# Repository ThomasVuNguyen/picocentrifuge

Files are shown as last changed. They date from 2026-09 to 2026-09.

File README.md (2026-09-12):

# PicoCentrifuge

A 3D printed centrifuge for PBMC separation, run by a Raspberry Pi Pico.
Part of the Bloom wet lab loop.

Read GOAL.md first. BOM.md is the source of truth for parts.

Why this exists: blood goes in, PBMC comes out, PBMC meets the peptide, we find out if
the algorithm was right. This is the cheapest link in that chain and it should not be
the one that costs $3000.

- `GOAL.md` - the contract. question, deadline, artifact, kill date.
- `BOM.md` - parts. have / ordered / need / failed.
- `LOG.md` - build log, newest first.
- `logs/` - voice notes and transcripts.
- `photos/` - dated photos. the timestamp is the log entry.
- `posts/` - drafts. friday opens a PR here on fridays.
- `failed-iterations/` - dead designs. kept for the writeup, never pulled from.

CAD lives in Onshape, document "ComfyBloom", assembly tab "Centrifuge Assembly".

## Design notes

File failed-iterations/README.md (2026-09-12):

# Failed iterations

Dead centrifuge designs. Kept because the failure is the interesting part and it belongs
in the post. Do not pull numbers, parts or STLs out of here into the live build.

## BLOOM-2-fusion (Aug 2026)

Swinging-bucket design, four 15 mL conicals, generated in Fusion 360 by an agent off a
Jira ticket. Complete on paper: parametric file, STEP, nine STLs, assembly drawing, BOM,
and a reproducible Fusion API build script. Never built.

Design point was 150 mm tube radius, 1545 rpm, 400.3 x g, which needed a containment
vessel with 466 mm clear inside diameter. That is a restaurant stock pot.

Why it died: [***]

## loose-assets

Orphaned exports that were sitting in comfybloom/assets: an early CAD render and two
STLs (base, rotor). No matching source file. Moved here rather than deleted.

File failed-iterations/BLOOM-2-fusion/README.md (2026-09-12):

# BLOOM-2 swinging-bucket centrifuge

Fusion 360 prototype for Ficoll/PBMC separation using four 15 mL conical tubes.

## Design point

- Tube mid-fluid radius: **150 mm**
- Exact calculated speed for 400 x g: **1544.4 rpm**
- Controller setpoint: **1545 rpm**
- Resulting RCF: **400.3 x g**
- Swing pivot radius: **86 mm**
- Rotor tip radius at speed: **218 mm**
- Minimum steel-pot inside diameter: **466 mm** (includes 15 mm radial clearance)

The four buckets are modeled in the at-speed horizontal position. Each bucket
rotates about an M3 tangential pivot and has a printed tab that contacts the arm
at 90 degrees. The clevis has 0.5 mm nominal side clearance to the 26 mm bucket
envelope. Use low-friction washers and tighten the nylock only enough to remove
axial play without pinching the bucket.

## Files

- `BLOOM-2_centrifuge_parametric.f3d` - Fusion archive with user parameters,
  shared arm/bucket components, named bodies, and the driven radius reference
- `BLOOM-2_centrifuge_assembly.step` - neutral assembly export
- `stl/` - printable parts; filenames state quantities or option
- `views/` - verified Fusion assembly views
- `bom.csv` - printed and purchased bill of materials
- `build_fusion.py` - reproducible Fusion API build script
- `../../../output/pdf/BLOOM-2_centrifuge_assembly_drawing.pdf` - assembly drawing,
  dimensions, BOM, print notes, and validation plan

## Print setup

- Material: PETG only; dry filament before printing.
- Chassis, hub, and arm: print flat as exported, 0.2 mm layers, 6 perimeters,
  8 top/bottom layers, 70-100% infill. Use 100% around bolt and pivot zones.
- Bucket: print on its side as exported so the principal tensile load runs in
  the layer plane. Use supports under the pivot lug and bore; 6 perimeters and
  100% infill at the lug/stop.
- Print all four arms in one job and all four buckets in one job with identical
  slicer settings. Deburr without removing asymmetric amounts of material.
- Match printed buckets to **+/-0.5 g**. Match opposing loaded tubes to
  **+/-0.1 g** before every run.

## Assembly

1. Press two 608ZZ bearings into the 22.2 mm chassis seats and preload them on
   the 8 mm shaft without side-loading either bearing.
2. Bolt four identical arms to the hub using two M3 fasteners per arm.
3. Install each bucket with an M3x45 pivot, two low-friction washers, and a
   nylock nut. Verify every empty bucket falls freely from vertical to the same
   hard stop by gravity alone.
4. Fit either the direct-drive plate/coupler or the offset 12T:60T gear plate.
   The same four-hole hub interface accepts either configuration.
5. Mount the IR sensor on the tall boss with a 4-8 mm gap to the underside
   target. Mount the MPU-6050 rigidly on the two-hole chassis boss.
6. Install the assembly inside a lidded steel pot with at least 466 mm clear ID.

## Drivetrain notes

Start with direct drive only if the A2212/30 A sensorless ESC starts the fully
loaded rotor smoothly and holds 1545 rpm without desynchronization. Configure a
smooth throttle ramp and coast-only stop; disable active braking. If direct
drive stutters, use the 12T:60T 5:1 option. The included gear STLs are mounting
and fit prototypes with simplified teeth; regenerate/verify true module-1
involute profiles before sustained running.

## Validation gate

This is an engineering prototype, not a certified medical device. Do not begin
with blood. First verify fastener retention, free/equal swing, empty balance,
loaded balance, sensor shutdown, containment, and a guarded overspeed test.
Then run four mass-matched tubes with dyed water over glycerol for 30 minutes at
1545 rpm and coast for more than two minutes. A clean interface is the pass
condition; a smeared or absent interface is a fail.

Made by Codex GPT 5.6 Sol High

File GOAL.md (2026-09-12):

# PicoCentrifuge

PROBLEM STATEMENT:

The Bloom wet lab loop needs PBMC out of whole blood. That needs a centrifuge holding
400 x g for 30 minutes with a slow coast. Used lab centrifuges run $800 to $3000.
I already own the motor, the ESC, the Pico and a printer.

WHAT I AM BUILDING:

A 3D printed centrifuge. Brushless motor sitting in the base housing, 5x8 coupler up to
an 8 mm rod, bearings in a holder, four-arm rotor on top. Speed held closed loop by a
Raspberry Pi Pico reading an IR tach. MPU-6050 on the chassis for imbalance shutdown.
Runs inside a lidded containment vessel.

CAD OF RECORD:

Onshape, document "ComfyBloom", workspace Main, assembly tab "Centrifuge Assembly".
458 instances. Tabs: Centrifuge, Components, Base, 5X8_COUPLER, Centrifuge Assembly.

URL: https://cad.onshape.com/documents/7f68ca2c53fefee57657ef1a/w/1be7287435b32af101e9f2c0/e/be93f421865ffb81668b9cbd

This is the only live design. Everything in failed-iterations/ is dead, do not pull
numbers out of it.

DESIGN POINT:

The requirement is 400 x g at the tube mid-fluid line, held 30 minutes, coast over
2 minutes. RPM falls out of whatever the real rotor radius is:

    rpm = sqrt( RCF / (1.118e-5 * r_cm) )

- Tube mid-fluid radius: [***] measure it off the Onshape assembly
- Setpoint rpm: [***] compute from the above, then round to the controller step
- Material: PETG only, dried

Do not carry the 150 mm / 1545 rpm numbers forward. Those belong to a dead design.

OUTCOME:

A clean Ficoll interface on a dyed-water-over-glycerol run at the setpoint for 30 min.
Smeared or absent interface is a fail. That is the only pass condition that matters.

FRIDAY CONTRACT:

- QUESTION: can a printed rotor on the A2212 hold the setpoint loaded and balanced for 30 min?
- DEADLINE: [***] must be external. grant deadline, a call with a lab, or a date I say
  out loud to Javi at standup. a date I set for myself is an intention, not a deadline.
- ARTIFACT: posts/ writeup, published whether it works or not
- FEEDS: bloom wetlab loop, maker press (SERVO / Hackaday), O-1A original contribution
- KILL DATE: [***]
- BLOCKED-ON-SHIPMENT is a valid state, it is not a stall

VALIDATION GATE:

No blood until all of these pass, in order:

1. fastener retention after 10 min unloaded
2. rotor runs true, no visible wobble at setpoint
3. empty balance, then loaded balance at +/-0.1 g on opposing tubes
4. MPU-6050 shutdown triggers on a deliberate imbalance
5. guarded overspeed test with the lid closed
6. dyed water over glycerol, setpoint, 30 min, coast over 2 min

Engineering prototype, not a certified device. Lid closed for every powered test.

OPEN DESIGN QUESTIONS:

- The assembly has modeled bearings (INNER RACE, OUTER RACE, RETAINER, 8 balls). Are
  those getting printed, or are they a fit model for a real 608 / 8 mm bearing? Printed
  races at 1500+ rpm under a loaded rotor is the thing I would not risk.
- Containment vessel: what is it and what is the clear ID. This killed the last design.
- Rotor is fixed-angle in the render, not swinging. Confirm that is intentional; it
  changes the interface quality on a Ficoll gradient.

NOTES FOR AI AGENTS:

- BOM.md is the source of truth for parts, not the CAD. Reconcile, do not generate.
- Do not write into this file unless I ask, or unless filling a [***].

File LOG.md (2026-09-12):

# Log

Newest first. Voice notes go in logs/ and get transcribed. Photos go in photos/, dated,
no captions needed.

## 2026-09-11 - moved to Onshape, BLOOM-2 retired

Rebuilt the whole thing in Onshape. Document "ComfyBloom", assembly "Centrifuge Assembly",
458 instances. Different architecture: motor sits in the base housing with the ESC, 5x8
coupler up to an 8 mm rod, bearings in a holder, four-arm rotor on top. M4 hardware.

BLOOM-2 and the loose STLs moved to failed-iterations/. Nothing gets pulled out of there.

## 2026-08-09 - BLOOM-2 finished on paper, never built

Agent-generated swinging-bucket design in Fusion off a Jira ticket. Complete package:
parametric file, STEP, nine STLs, assembly drawing, BOM, build script. Needed a 466 mm
clear ID containment vessel. Dead.

## 2026-08-08 - A2212 ramp test on Pico

Motor and ESC ran clean off a MicroPython ramp script. No load, no rotor. Confirmed the
drivetrain is not the hard part.

## 2026-08-08 - decided to build rather than buy

Used lab centrifuges run $800 to $3000. I already own the motor, ESC, Pico and printer.
Stripped it to the physical function: hold 400 x g for 30 minutes with a slow coast and
do not throw a tube. That is a motor, a balanced rotor, a speed loop and a lid.

## Open blockers

1. blood sample and tumor sample
2. containment vessel, clear ID still unknown

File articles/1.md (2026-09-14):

PicoCentrifuge - a DIY centrifuge with Raspberry Pi Pico
=======================================================
Sep 13, 2026 · Budget: $50

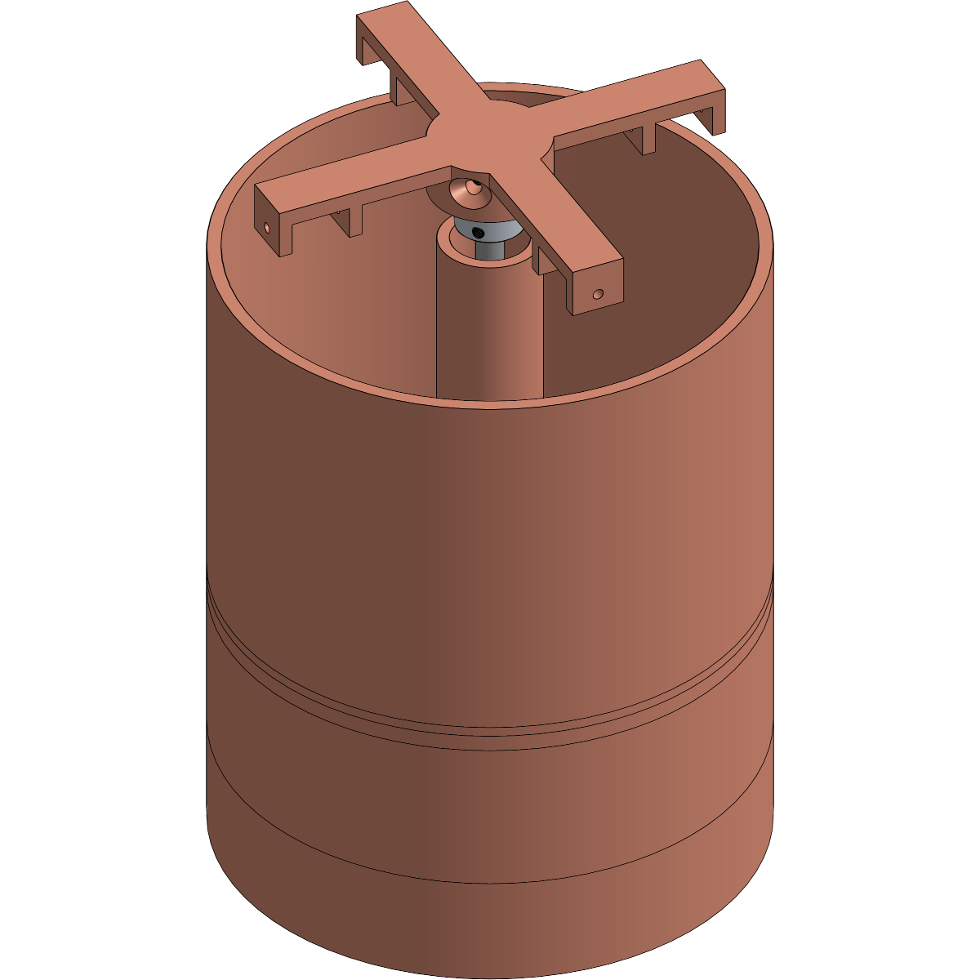
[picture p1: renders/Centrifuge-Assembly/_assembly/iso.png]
PicoCentrifuge full assembly


A centrifuge for blood processing. Drone motor, a Pico, and a 3D printer.

---

## Background

3 days ago was marking 13 years of my mom passing. The moment cancer took her away, I realized it's my life mission to find the definitive cure for cancer.

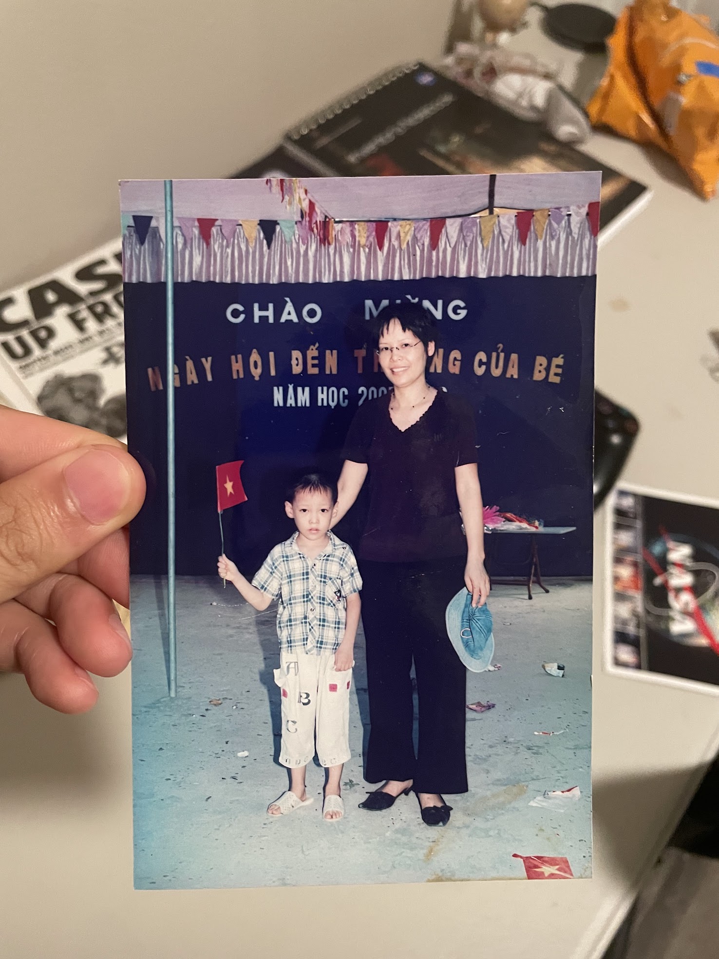
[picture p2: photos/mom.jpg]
Mom


That goal has not changed. What I'm building here is a part of an experiment to create customized neoantigens to kill specific cancer cells in specific few people. 

I'm building [Bloom](https://github.com/ThomasVuNguyen/comfybloom). It takes a patient's sequencing data, finds the mutations, predicts which peptides will trigger an immune response. That part is software. Proving it works is wet lab.

The wet lab loop is simple. Show a peptide to T cells and see if they react:

- Get the T cells. Draw blood, spin it over a density gradient, pull the PBMC layer
- Keep them alive. 37°C, sterile, fed
- Introduce the peptide. Synthesized peptide + cells in a well
- Read the response. Did they secrete IFN-γ? ELISpot plate tells you

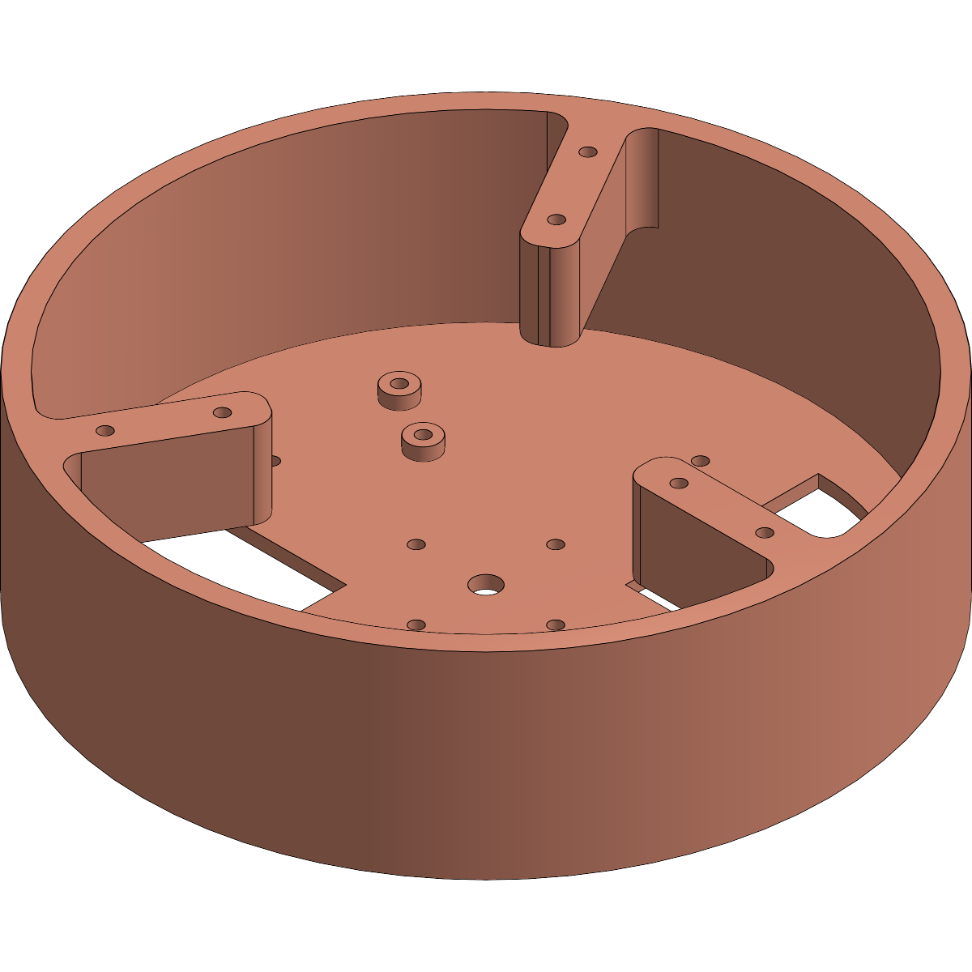
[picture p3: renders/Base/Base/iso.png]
The base housing - motor mounts in the center, ESC tucks underneath


Step 1 is a centrifuge. A used lab centrifuge that fits 15 mL conical tubes goes for $800-$3,000 on eBay. That's the most expensive piece in a DIY wet lab that otherwise costs under $500 from Amazon.

I already own an A2212 brushless motor, a 30A ESC, a Raspberry Pi Pico, and a 3D printer.

The physics is simple. Spin tubes in a circle fast enough that centripetal acceleration separates blood by density. PBMC isolation over Ficoll needs about 400 × g for 30 minutes with a slow coast down.

So I'm building one.

---

## The first design that died

I gave an AI agent a task: design a swinging-bucket centrifuge for four 15 mL conicals at 400 × g. It came back with a complete package in Fusion 360. Parametric file, STEP exports, nine STLs, assembly drawing, BOM, build script. On paper it was beautiful.

On paper it also needed a containment vessel with a 466 mm clear inside diameter. That's an 18-inch restaurant stock pot. The rotor radius was 150 mm, which put the setpoint at 1,545 rpm. Reasonable for the motor, but the whole assembly was enormous. Half the bench gone.

I stared at that for a while and moved on. That design lives in `failed-iterations/BLOOM-2-fusion`. I keep dead designs around because the failure is the interesting part.

---

## What I'm actually building

I rebuilt everything from scratch in Onshape. Much more compact.

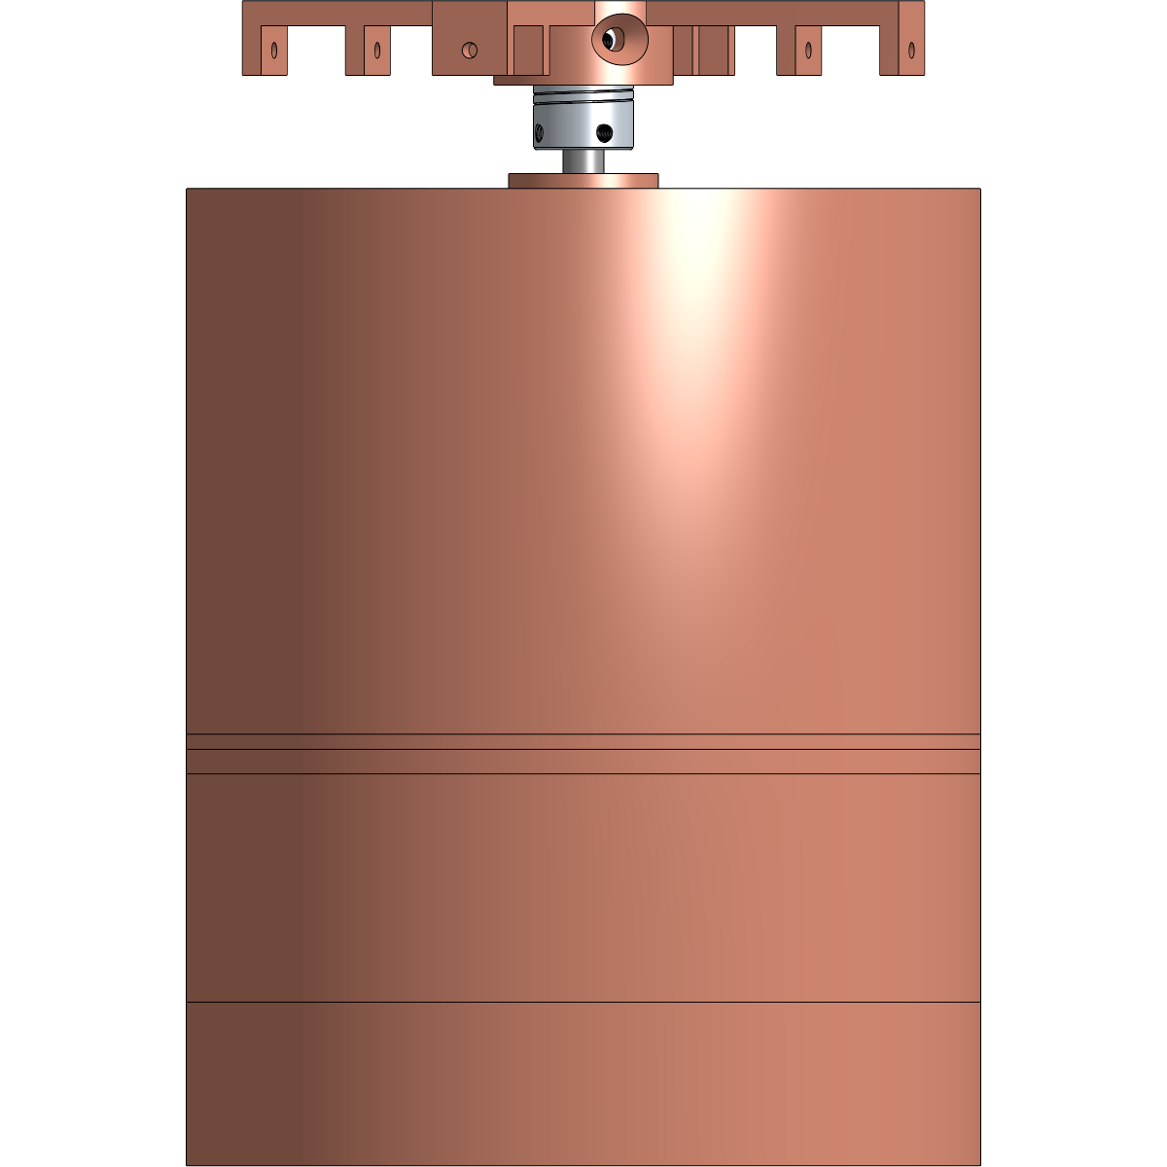
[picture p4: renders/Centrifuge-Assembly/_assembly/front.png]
Front view - you can see the rotor on top, coupler and rod in the middle, containment pot around it, base housing at the bottom


Motor sits in the base housing with the ESC. A 5-to-8 mm rigid coupler goes up to an 8 mm steel rod. Bearings in a holder. Four-arm rotor on top. Whole thing sits inside a containment pot.

Fixed-angle design instead of swinging-bucket. You get a slanted interface on a Ficoll gradient and a harder draw with the pipette. Trade-off is worth it. Mechanically simpler, shorter, easier to balance. For a first prototype, simple wins.

Here's the real thing coming together. Motor, coupler, rod, wiring, all sitting inside the printed base:

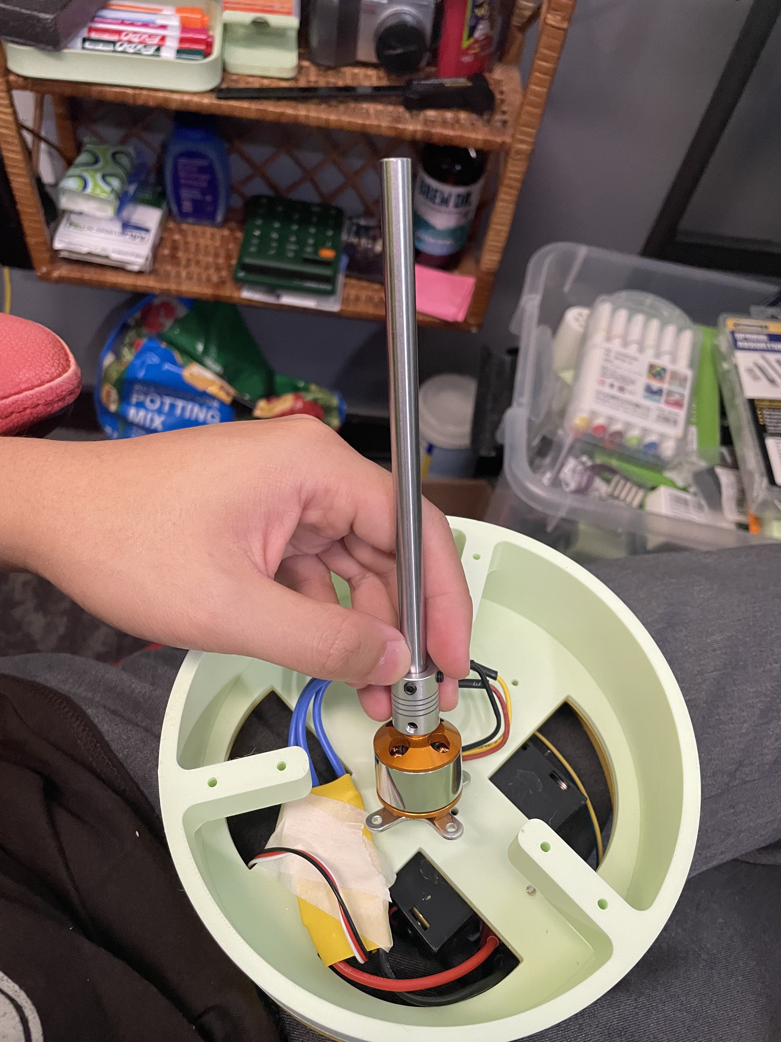
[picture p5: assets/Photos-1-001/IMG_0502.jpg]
Motor installed in the base - A2212 with the coupler and steel rod, ESC wiring tucked inside


And the fully assembled unit, lid closed:

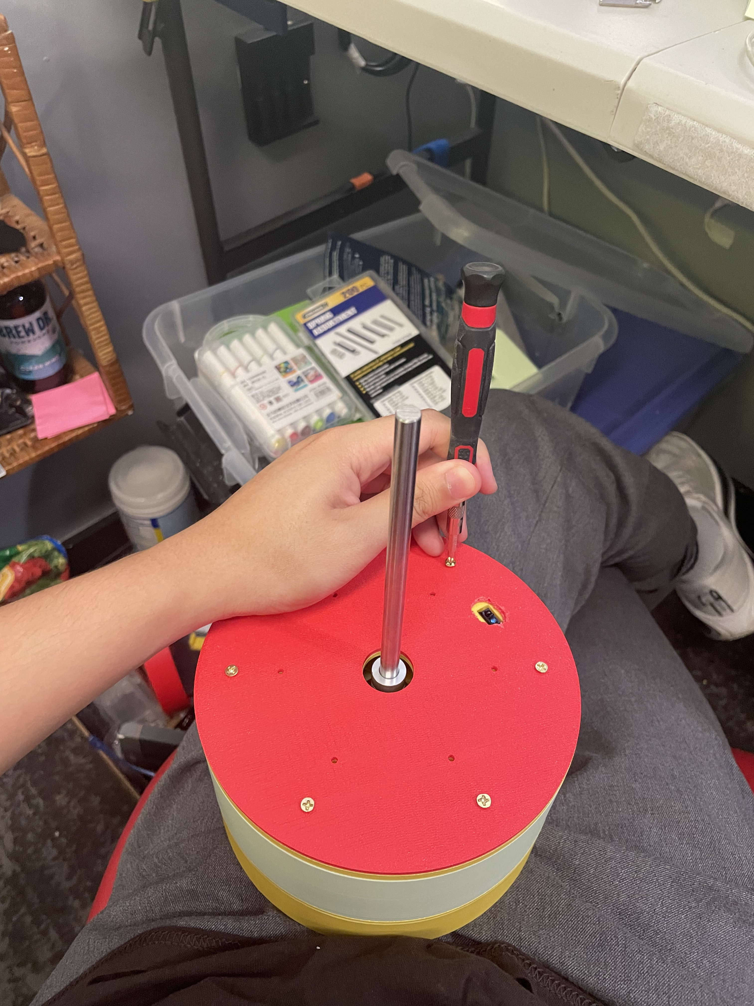
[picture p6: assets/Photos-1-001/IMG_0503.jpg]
Assembled PicoCentrifuge - lid screwed down, rod sticking out the top, ready for the rotor


---

## The rotor

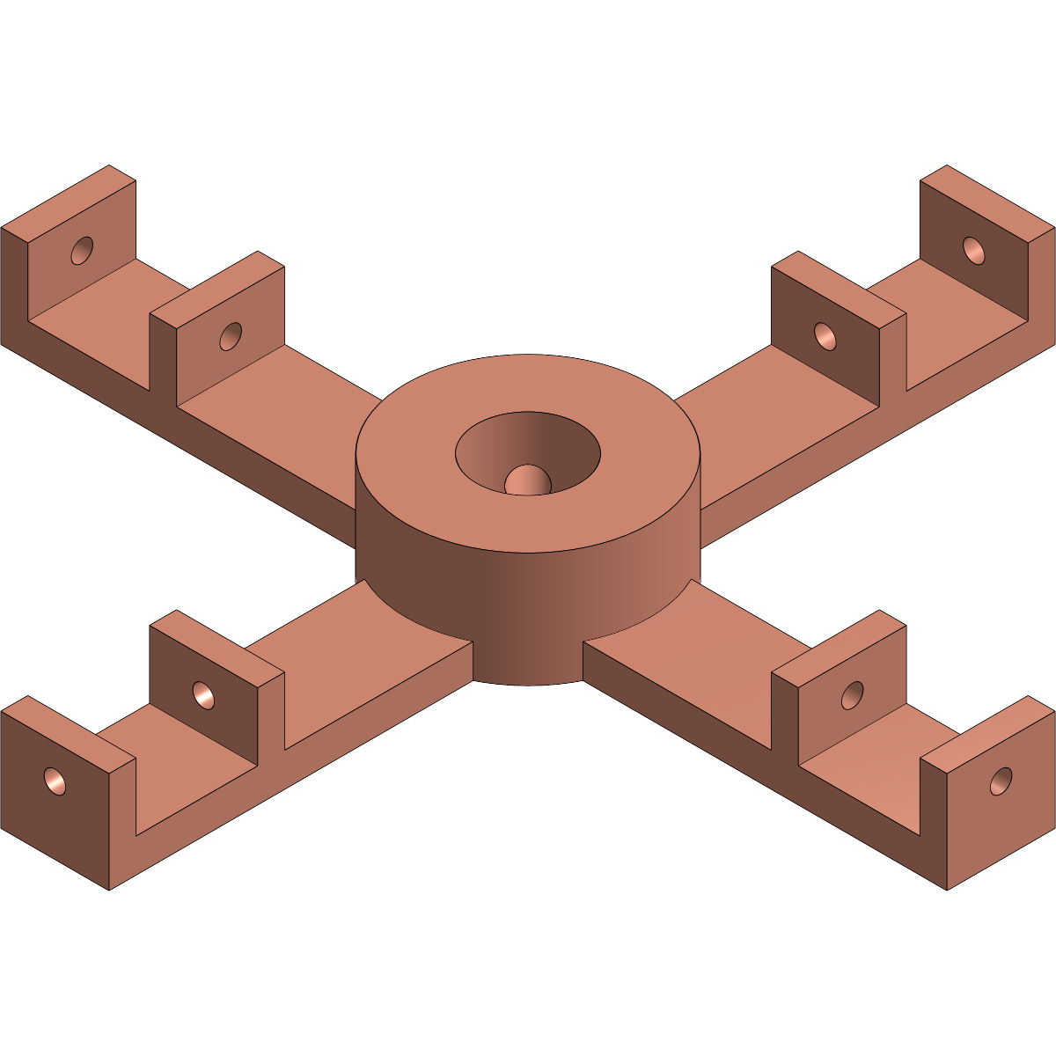
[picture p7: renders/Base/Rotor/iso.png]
Four-arm rotor - each arm cradles a 15 mL conical tube


Four-arm cross, 3D printed in PETG. Each arm holds a 15 mL conical tube (17 × 120 mm). Opposing tubes need to be matched to within ±0.1 g. Imbalance at 1,500+ rpm is how you throw a tube through a wall.

The rotor radius (center of rotation to mid-fluid line) determines the RPM setpoint:

```
rpm = sqrt( RCF / (1.118e-5 × r_cm) )
```

At 400 × g, smaller radius = higher RPM. The exact number comes from measuring the real rotor off the Onshape assembly.

---

## The drivetrain

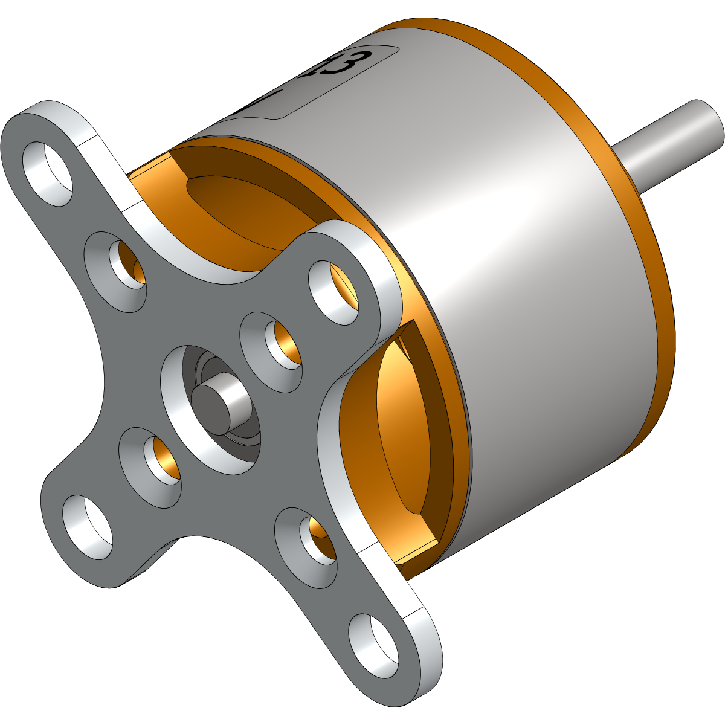
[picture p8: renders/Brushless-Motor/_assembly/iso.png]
A2212 brushless motor - this is a drone motor, way more torque than I need


The A2212/1000KV is a drone motor. Rated for way more RPM than I need. The ESC has brake disabled and a smooth ramp programmed. You do not hard-brake a centrifuge, ever. Coast over 2 minutes minimum, or you disturb the gradient you just spent 30 minutes forming.

Here's the actual motor with the 5-to-8 mm coupler already attached. You can read "A2212/1000KV" right on the label:

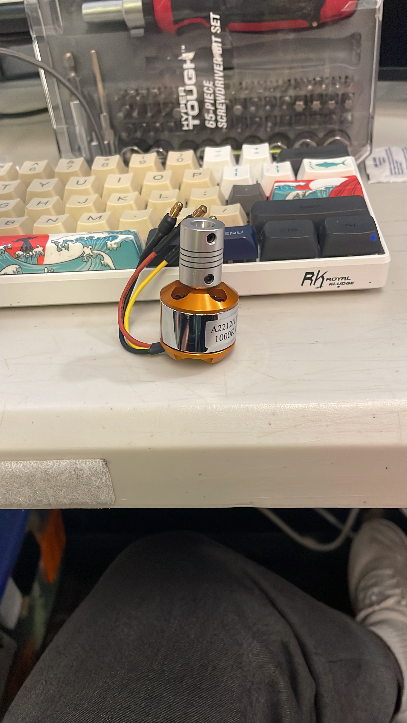
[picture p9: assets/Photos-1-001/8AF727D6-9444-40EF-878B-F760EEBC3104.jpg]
The real A2212 motor with coupler attached, sitting on my desk


I tested the motor and ESC on the Pico before designing anything else. MicroPython ramp script, no load, no rotor. Just confirming the drivetrain works:

```python
from machine import Pin, PWM
import time

esc = PWM(Pin(1))
esc.freq(50)

def us(val):
    esc.duty_u16(int(val / 20000 * 65535))

# arm
us(1000)
time.sleep(3)

# ramp up
for throttle in range(1060, 1300, 20):
    us(throttle)
    time.sleep(2)

# ramp down
for throttle in range(1300, 1040, -20):
    us(throttle)
    time.sleep(2)

us(1000)
time.sleep(1)
esc.deinit()
```

Ran clean. The motor coils sing at higher throttle. That's normal, not an alarm.

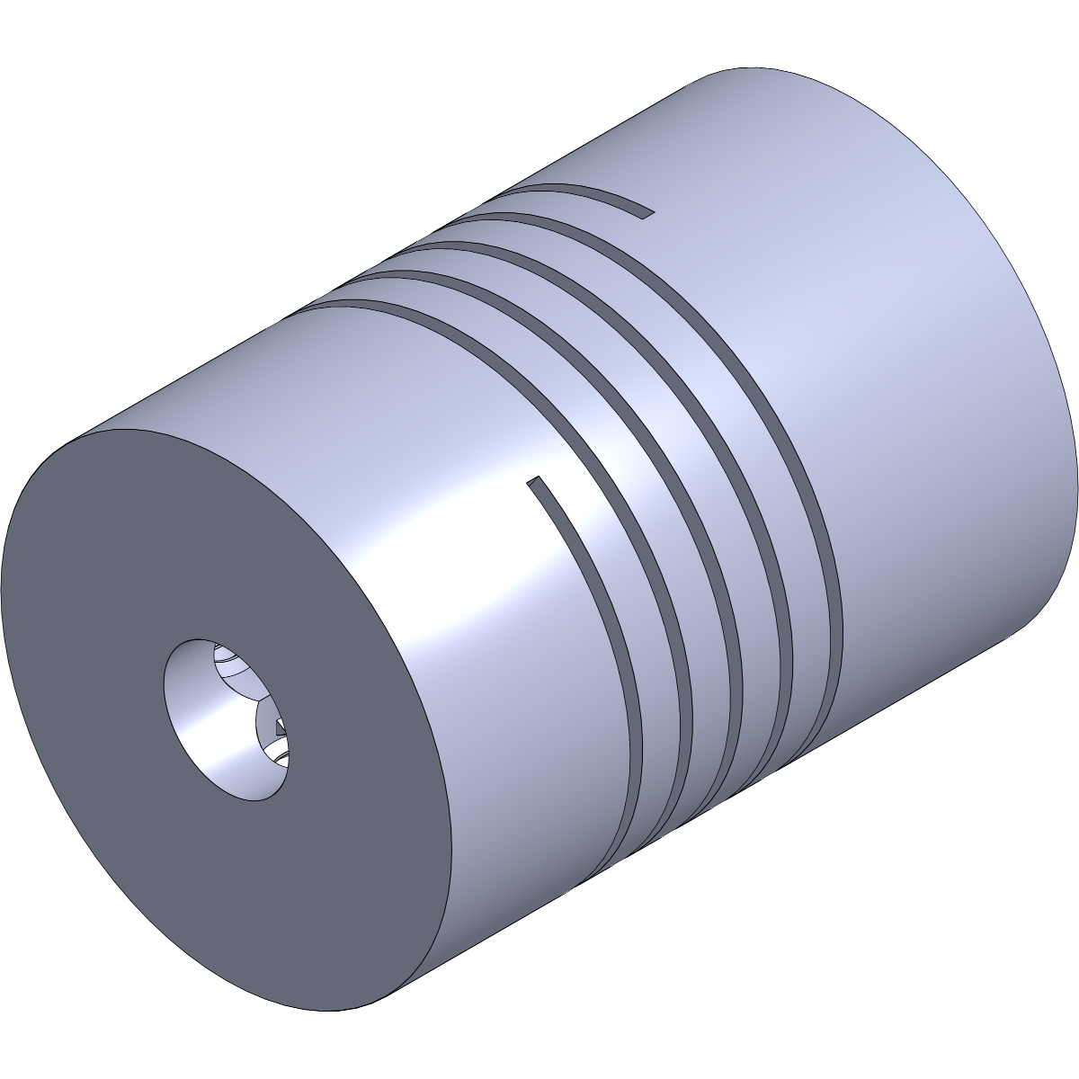
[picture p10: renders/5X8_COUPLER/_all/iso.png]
The 5-to-8 mm coupler - connects the motor shaft to the steel rod


And the aluminum couplers I ordered. These are the real ones, not printed:

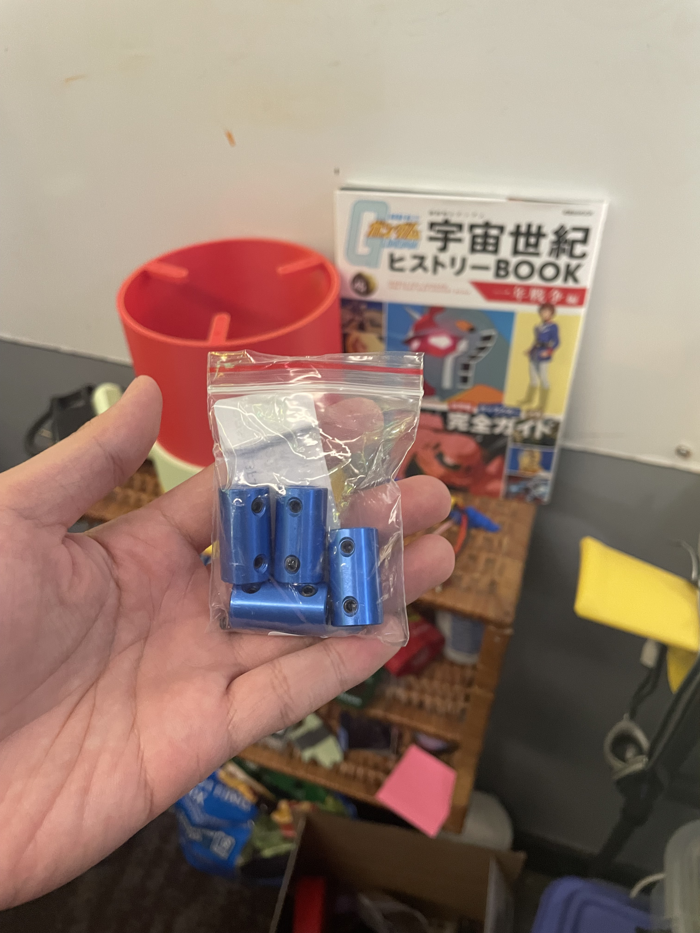
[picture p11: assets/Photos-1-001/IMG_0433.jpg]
5-to-8mm aluminum rigid couplers - buy these, do not print them


---

## Speed control

The setpoint RPM needs to be held closed-loop for 30 minutes. IR reflective sensor pointed at the underside of the rotor gives a tach signal. The Pico counts pulses and adjusts the ESC throttle to maintain target. Textbook PID loop.

---

## Safety

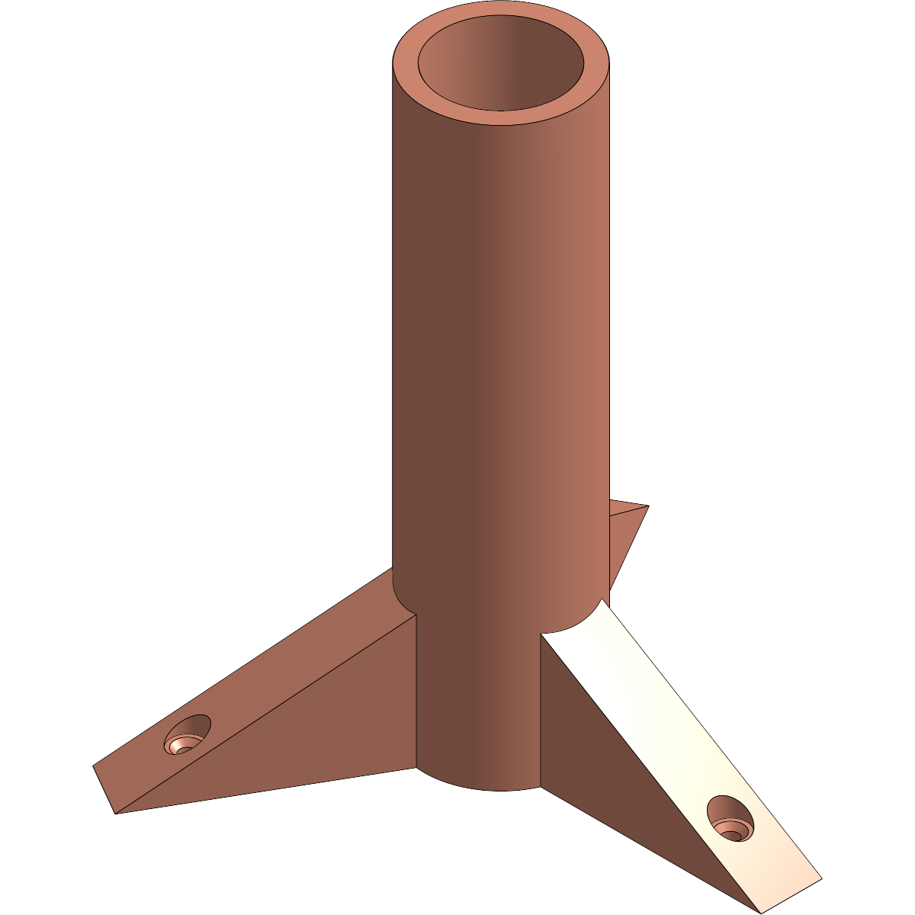
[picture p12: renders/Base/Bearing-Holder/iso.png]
Bearing holder - this sits between the base and the rotor, holds the 8mm rod steady


MPU-6050 accelerometer/gyro sits on the chassis. Flat, rigid, bolted near the bearing holder. NOT on the rotor. It's a vibration sensor: if something comes loose or a tube shifts, vibration signature changes and the Pico cuts motor power. Imbalance shutdown.

The whole assembly runs inside a lidded containment vessel. Lid closed for every powered test, no exceptions.

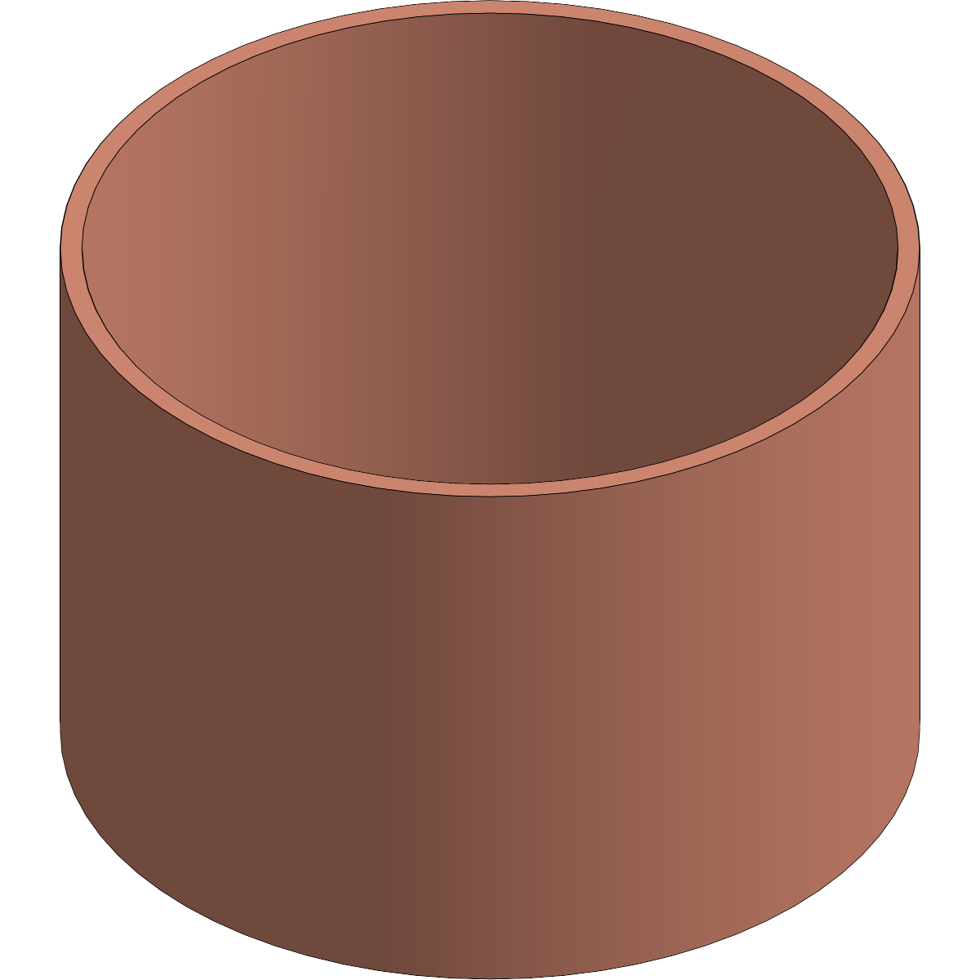
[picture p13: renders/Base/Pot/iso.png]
Containment pot - everything spins inside this


---

## Printing

All structural parts are PETG on the Bambu A1 mini. Filament has to be dried or you get moisture bubbles that become stress risers at speed. Not optional.

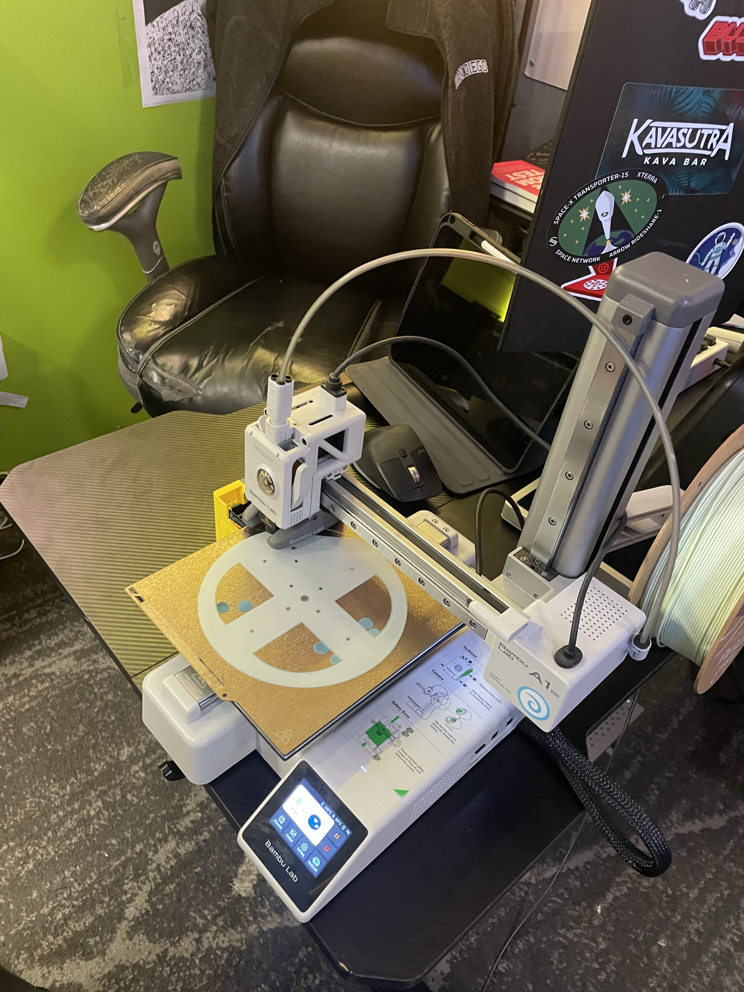
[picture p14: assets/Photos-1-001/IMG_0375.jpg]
Printing the base on the Bambu A1 mini


Opposing rotor arms are printed in the same job so they shrink identically. Matched sets, not mix and match.

---

## The parts

What I already have:

| Part | Notes |
|---|---|
| [A2212 brushless motor (1000 KV, 5 mm shaft)](https://www.amazon.com/dp/B0D2W24DFX) | Ramp tested, ran clean |
| [30A sensorless ESC](https://www.amazon.com/dp/B08DXYLFQQ) | Brake disabled, smooth ramp |
| [Raspberry Pi Pico](https://www.amazon.com/s?k=Raspberry+Pi+Pico) | MicroPython |
| 2S LiPo (~7.4V) | Needs a fuse and physical disconnect |
| Bambu A1 mini | PETG, dried filament |
| [5-to-8 mm rigid coupler](https://www.amazon.com/s?k=5mm+to+8mm+rigid+shaft+coupler) | Real aluminum coupler, in hand; do not print |
| [Bearings (size TBD)](https://www.amazon.com/s?k=608+bearing) | Real bearings in hand; confirm size before final assembly |

What I still need:

| Part | Notes |
|---|---|
| [8 mm ground steel rod](https://www.amazon.com/s?k=8mm+ground+steel+rod) | ~100-125 mm |
| [M4 × 6 screws](https://www.amazon.com/s?k=M4x6+screw) | Assembly hardware |
| [IR reflective sensor](https://www.amazon.com/s?k=TCRT5000+IR+reflective+sensor) | Tachometer, 4-8 mm gap |
| [MPU-6050](https://www.amazon.com/s?k=MPU-6050+GY-521+accelerometer) | Imbalance detection |
| [15 mL conical tubes (×4)](https://www.amazon.com/s?k=15mL+conical+centrifuge+tubes) | Opposing tubes matched to ±0.1 g |
| Containment vessel + lid | Measuring rotor tip radius first |
| [Glycerol + dye](https://www.amazon.com/s?k=glycerol+food+grade) | Validation run before any blood |

Printed parts (PETG, dried, matched sets in one print job):

| Part | Onshape name |
|---|---|
| Base | Base |
| Base Cover | Base Cover |
| Bearing Holder | Bearing Holder |
| Top | Top |
| Rotor | Rotor |

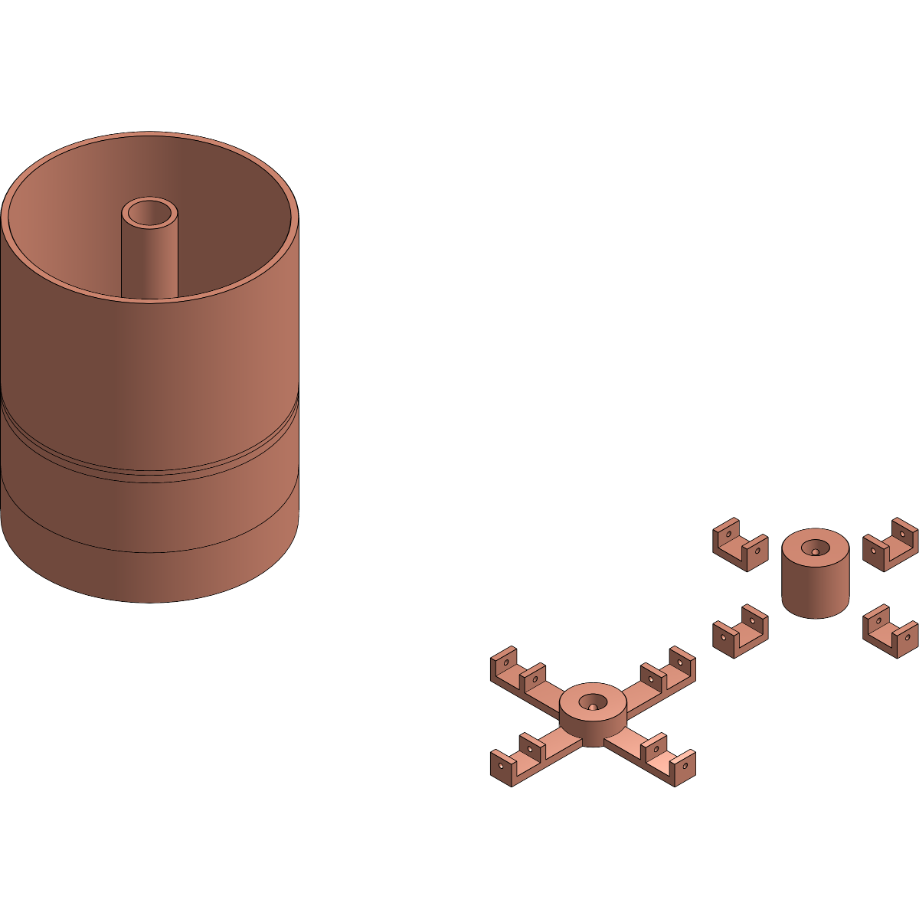
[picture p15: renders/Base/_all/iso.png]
All the printed parts and containment pot together


---

## Validation plan

No blood until all of these pass, in order:

- Fastener retention after 10 minutes unloaded
- Rotor runs true, no visible wobble at setpoint
- Empty balance, then loaded balance at ±0.1 g on opposing tubes
- MPU-6050 shutdown triggers on a deliberate imbalance
- Guarded overspeed test with the lid closed
- **The real test**: dyed water over glycerol, setpoint RPM, 30 minutes, coast over 2 minutes

Last one is the real test. Clean interface = the device holds enough g-force long enough to separate by density. Smeared or no interface = fail.

Only after that does it get real blood.

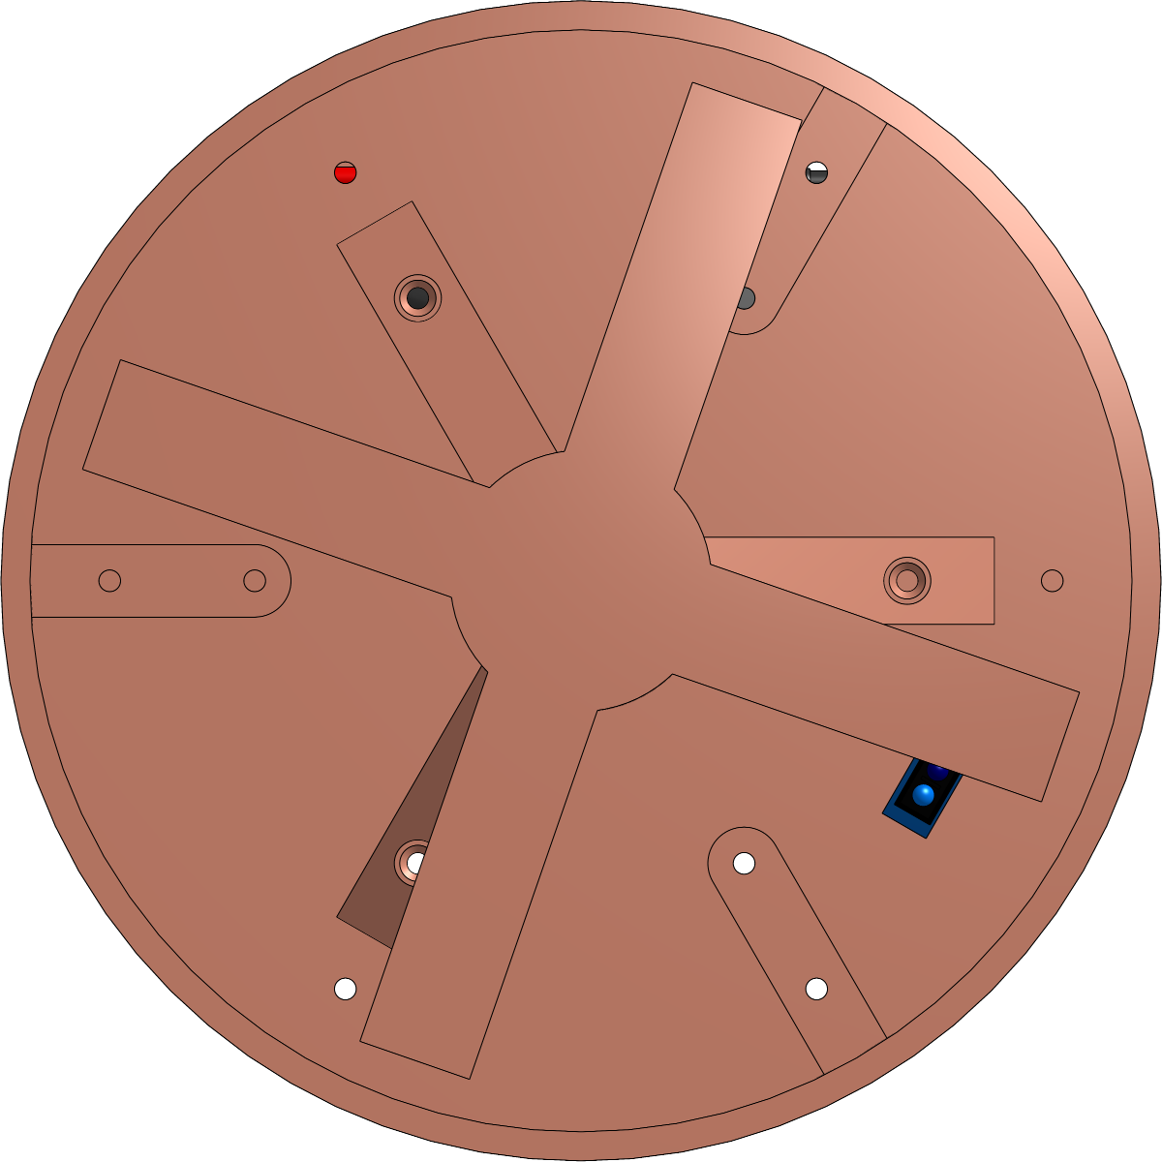
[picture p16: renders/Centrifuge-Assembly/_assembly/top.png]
Top view - the rotor cross, base cover with bearing hole, electronic hub layout


---

## Why build this in public

A used lab centrifuge would've been easier. I looked at OpenFuge and the other 3D-printed centrifuge designs. Most can't fit 15 mL conical tubes, which is what you need for PBMC washing steps.

If this works, it drops the cost of blood processing from $800-$3,000 to about $50 in parts. Every piece of cancer research infrastructure that can be open-sourced and made cheap should be.

The Bloom pipeline is already open source. The computational prediction is free. If the wet lab validation can also be done with printed parts and a Pico, then the barrier to testing a neoantigen candidate goes from "you need a lab" to "you need a bench and some patience."

---

## What's next

Before any blood goes in, I need to complete the validation gate: mechanical retention, balance, imbalance shutdown, guarded overspeed, and the dyed-water-over-glycerol separation test. If those pass, the next step is to get a blood sample and run the real blood-processing test. I'll document what happens here.

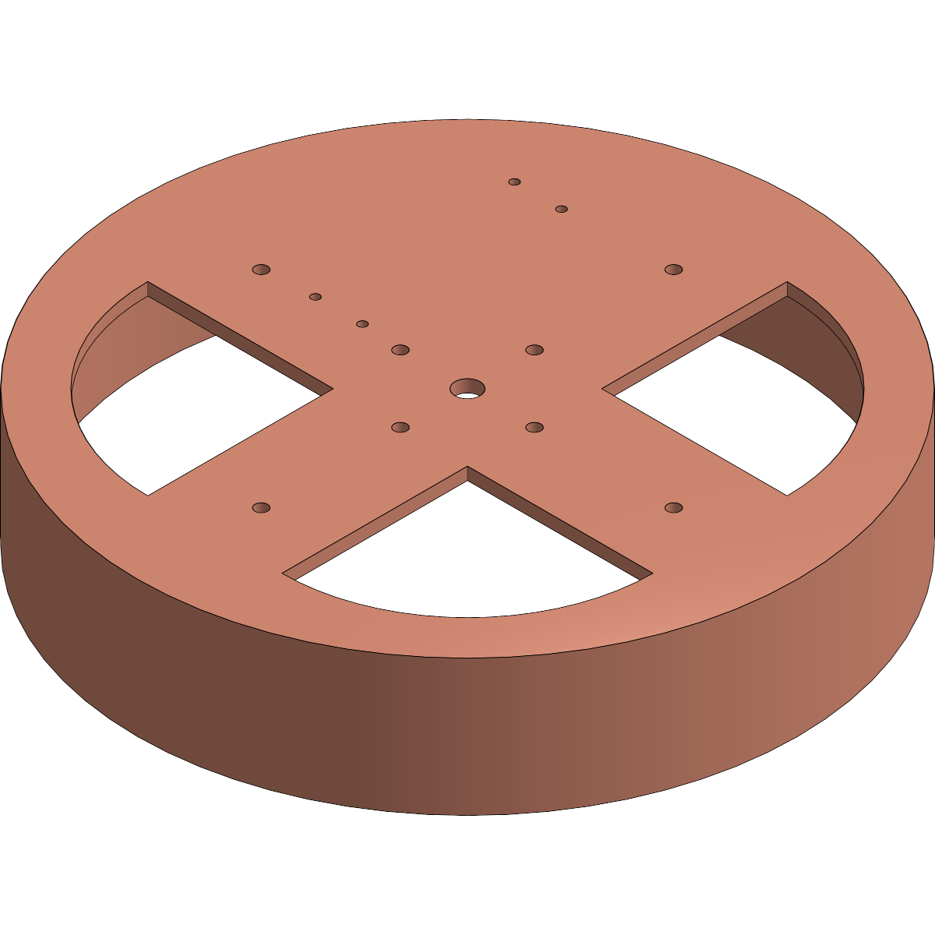
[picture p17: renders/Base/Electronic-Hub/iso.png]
Electronic hub - where the Pico, ESC wiring, and sensor connections live


**CAD files**: public on Onshape - [ComfyBloom Centrifuge Assembly](https://cad.onshape.com/documents/7f68ca2c53fefee57657ef1a/w/1be7287435b32af101e9f2c0/e/be93f421865ffb81668b9cbd)

**Code**: will go in this repo as the firmware matures past the ramp test

**BOM, build log, and voice notes**: all in the repo at [github.com/ThomasVuNguyen/picocentrifuge](https://github.com/ThomasVuNguyen/picocentrifuge)

If you're building something similar, or if you're working on cancer immunotherapy validation and the cost of equipment is stopping you, reach out. This should not be a solo effort.

---

## Source code, useful links & sponsors

- [Onshape CAD (view-only)](https://cad.onshape.com/documents/7f68ca2c53fefee57657ef1a/w/1be7287435b32af101e9f2c0/e/be93f421865ffb81668b9cbd)
- [GitHub repo](https://github.com/ThomasVuNguyen/picocentrifuge)
- [Bloom pipeline](https://github.com/ThomasVuNguyen/comfybloom)

---

With intelligence and enthusiasm, anything is possible

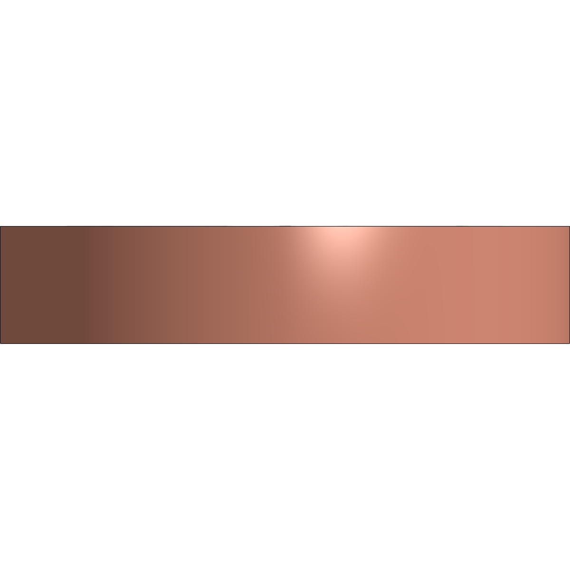
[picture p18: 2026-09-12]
renders/Base/Electronic-Hub/right.png

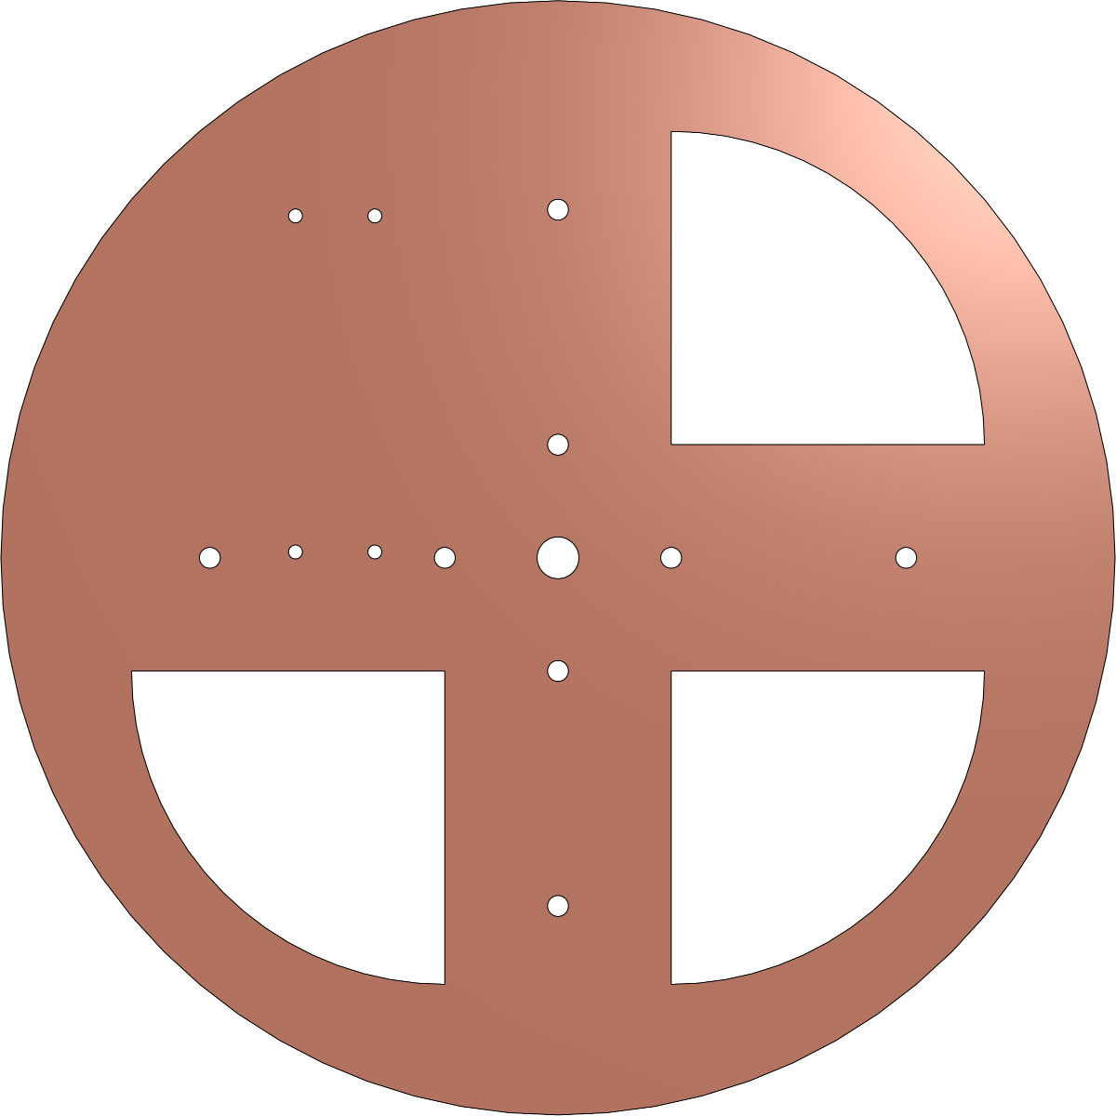
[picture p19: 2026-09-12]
renders/Base/Electronic-Hub/top.png

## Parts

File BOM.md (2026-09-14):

# BOM

Source of truth for parts. Not generated from CAD. Friday reconciles this against the
Onshape assembly and tells me what is unaccounted for.

Status: `have` / `ordered` / `need` / `failed`

## Owned

| Item | Qty | Spec | Status | Notes |
|---|---|---|---|---|
| A2212 brushless motor | 1 | 1000 KV, 5 mm shaft | have | ramp tested on Pico, ran clean |
| Sensorless ESC | 1 | 30 A | have | brake disabled, smooth ramp programmed |
| Raspberry Pi Pico | 1 | MicroPython | have | running the ramp script |
| 2S LiPo | 1 | ~7.4 V | have | needs a fuse and a physical disconnect |
| Printer | 1 | Bambu A1 mini | have | PETG, dry the filament |
| Coupler 5 to 8 mm | 1 | rigid | have | real aluminum coupler is in hand; do not print |
| Bearing | 2 | [***] confirm size | have | real bearings are in hand; confirm size before final assembly |

## Need

| Item | Qty | Spec | Status | Notes |
|---|---|---|---|---|
| 8 mm rod | 1 | ~100-125 mm | need | ground steel preferred |
| M4 x 6 screw | [***] | - | need | assembly uses M4x6-Vis throughout |
| IR reflective sensor | 1 | optical tachometer | need | 4-8 mm gap to an underside target |
| MPU-6050 | 1 | - | need | mount flat and rigid near the bearing holder. NOT next to the rotor |
| 15 mL conical tube | 4 | 17 x 120 mm | need | opposing tubes matched to +/-0.1 g |
| Containment vessel + lid | 1 | clear ID [***] | need | measure rotor tip radius first |
| Glycerol + dye | 1 | - | need | validation run, before any blood |

## Printed

PETG, dried. Print matched sets in one job with identical slicer settings.

| Part | Qty | Onshape name | Notes |
|---|---|---|---|
| Base | 1 | Base | houses motor and ESC |
| Base Cover | 1 | Base Cover | - |
| Bearing Holder | 1 | Bearing Holder | - |
| Top | 1 | Top | - |
| Rotor | 1 | Rotor | four arm cross. mass match arms |
| Corps | 2 | Corps | [***] what is this, label it |
| Cover / races / retainer | - | COVER, INNER RACE, OUTER RACE, RETAINER | see open question |

## Open questions

- **Bearings.** Real bearings are now in hand, but the size and part number still need to
  be confirmed before final assembly. The assembly models a full bearing: INNER RACE,
  OUTER RACE, RETAINER and 8 balls. Use the real bearings; printed races carrying a
  loaded rotor at 1500+ rpm is the one thing I would not risk.
- **Rotor angle.** Render looks fixed-angle, not swinging. Fixed-angle works for Ficoll
  but gives a slanted interface and a harder draw. Confirm it is intentional.
- **Containment vessel.** Already modeled as `Pot` in the Base studio, rotor sits inside
  it. Confirm the real-world part it is modeled from and put it in the Need table above.
  Sourcing this is what killed BLOOM-2.
- **Unnamed parts.** Base studio still has `Part 8`, `Part 9`, `Part 10`, `Part 11` and
  `fit tes`. Render filenames come from part names, so these read badly in a build log.

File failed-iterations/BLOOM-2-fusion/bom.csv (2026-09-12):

Category | Item | Qty | Specification | Notes
Printed | Chassis and bearing tower | 1 | PETG high infill | Includes IR pedestal and rigid MPU boss
Printed | Rotor hub | 1 | PETG solid at bolt zones | Four shared arm lands and drivetrain interface
Printed | Rotor arm | 4 | PETG high infill | Print together and mass match
Printed | Swing bucket | 4 | PETG high infill | 18.6 mm bore for 17 x 120 mm tube; print together
Printed | Direct motor plate | 1 optional | PETG | Use only for smooth direct-drive startup
Printed | Direct coupler | 1 prototype | PETG prototype | Commercial 3.17-to-8 mm coupler preferred
Printed | Gear motor plate | 1 optional | PETG | 36 mm nominal center distance
Printed | Driven gear | 1 optional | 60T module-1 prototype | Replace simplified teeth with validated involute
Printed | Motor pinion | 1 optional | 12T module-1 prototype | Replace simplified teeth with validated involute
Owned | A2212 brushless motor | 1 | 1000 KV | Ticket-specified
Owned | Sensorless ESC | 1 | 30 A | Disable brake and program smooth ramp
Owned | Battery | 1 | 2S LiPo approximately 7.4 V | Add fuse and physical disconnect
Owned | Bearing | 2 | 608ZZ 8 x 22 x 7 mm | Light preload only
Hardware | Shaft | 1 | 8 mm diameter x approximately 100-125 mm | Ground steel preferred
Hardware | Bucket pivot screw | 4 | M3 x 45 mm | Use smooth shank where possible
Hardware | Bucket pivot nylock nut | 4 | M3 | Do not pinch clevis
Hardware | Low-friction pivot washer | 8 | M3 PTFE or acetal | One each side of every bucket lug
Hardware | Arm-to-hub screw | 8 | M3 x 20 mm | With washers and nylock nuts
Hardware | Drive-interface screw | 4 | M3 x 16 mm | Shared direct/gear bolt pattern
Hardware | Motor/chassis screw set | 1 | M3 assorted | Fit selected plate and A2212 cross mount
Instrumentation | IR reflective sensor | 1 | Reflective optical tachometer | Align to rotor underside target
Instrumentation | MPU-6050 module | 1 | Rigid chassis mount | No vibration isolation
Consumable | 15 mL conical tube | 4 | 17 x 120 mm | Opposing loaded tubes matched to +/-0.1 g
Containment | Steel pot and lid | 1 | Minimum 466 mm clear inside diameter | Lid closed for every powered test

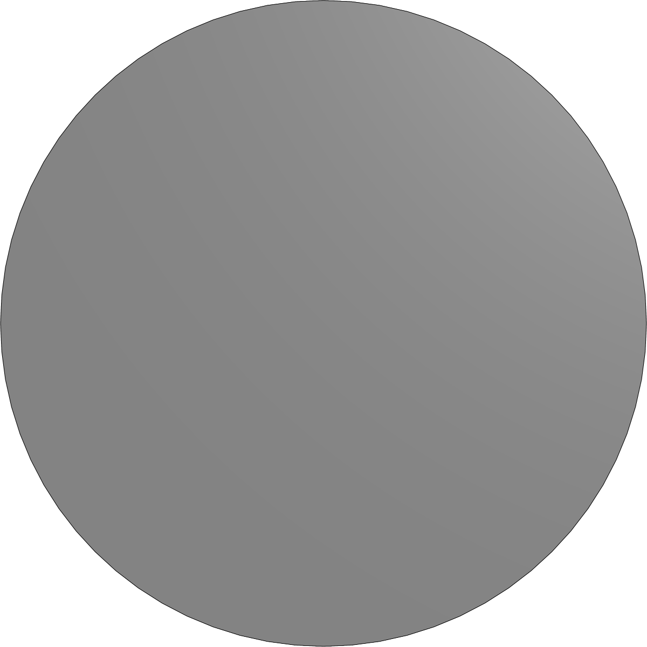
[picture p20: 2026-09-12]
renders/Other-Components/_all/top.png

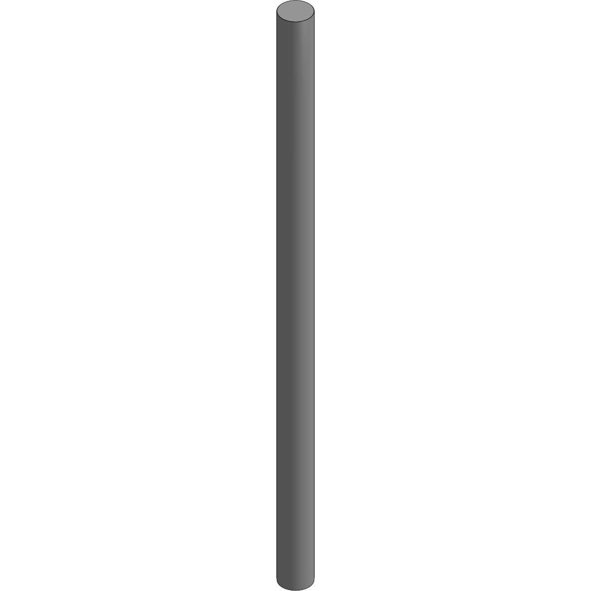
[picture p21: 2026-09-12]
renders/Other-Components/8mm-rod/iso.png

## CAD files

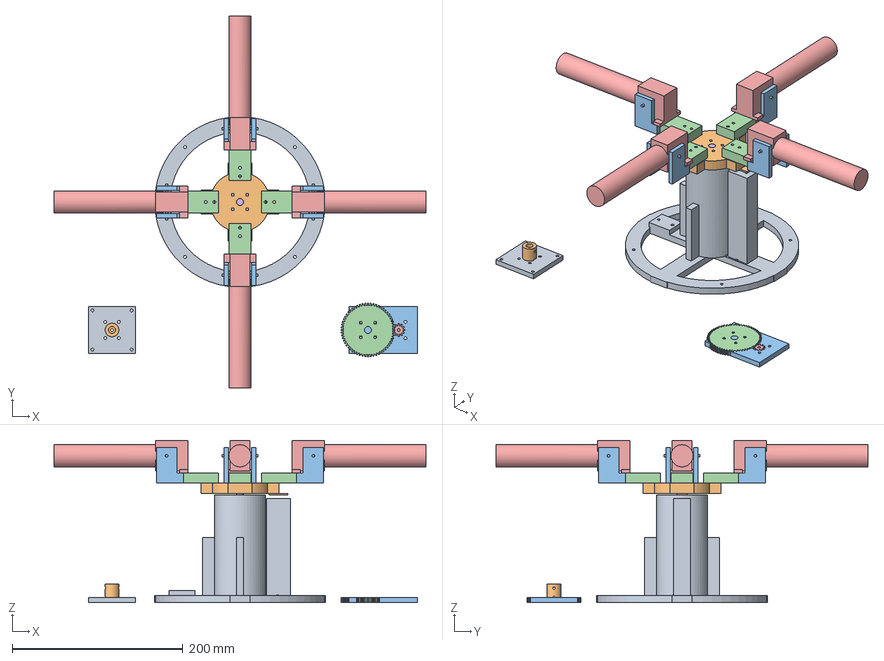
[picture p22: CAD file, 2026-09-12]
failed-iterations/BLOOM-2-fusion/BLOOM-2_centrifuge_assembly.step
436.0 x 436.0 x 190.0 mm

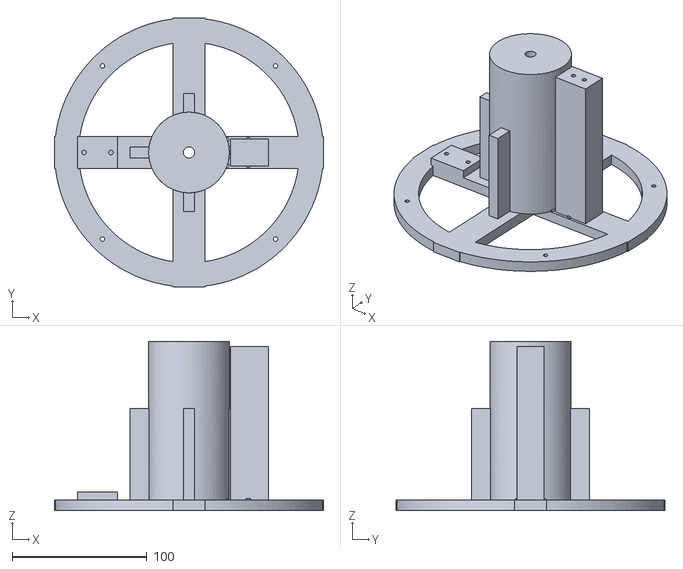
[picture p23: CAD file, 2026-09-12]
failed-iterations/BLOOM-2-fusion/stl/01_chassis_bearing_tower.stl
200.0 x 200.0 x 126.0

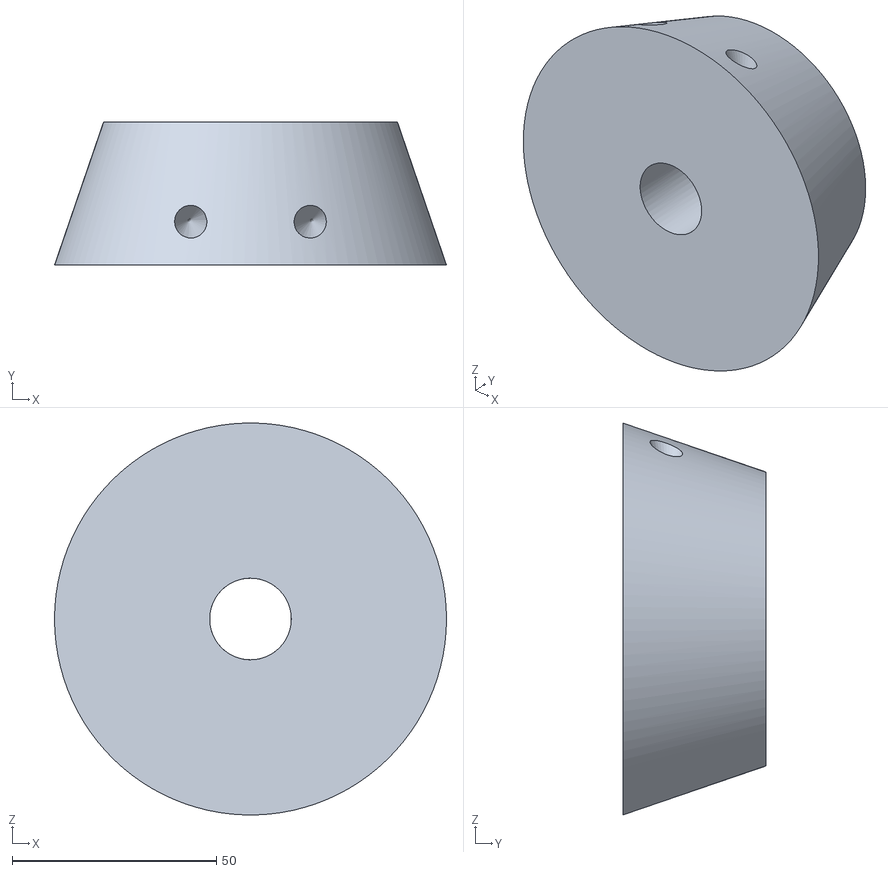
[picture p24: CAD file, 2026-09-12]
failed-iterations/loose-assets/centrifuge_rotor.stl
96.0 x 35.0 x 96.0

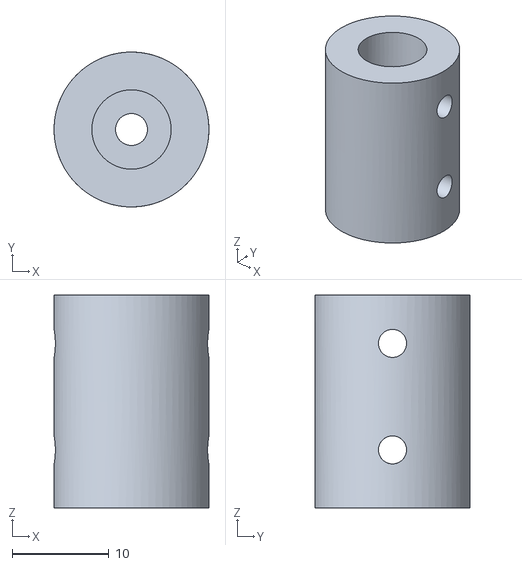
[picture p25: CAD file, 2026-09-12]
failed-iterations/BLOOM-2-fusion/stl/06a_direct_coupler_3p17_to_8mm.stl
16.0 x 16.0 x 22.0

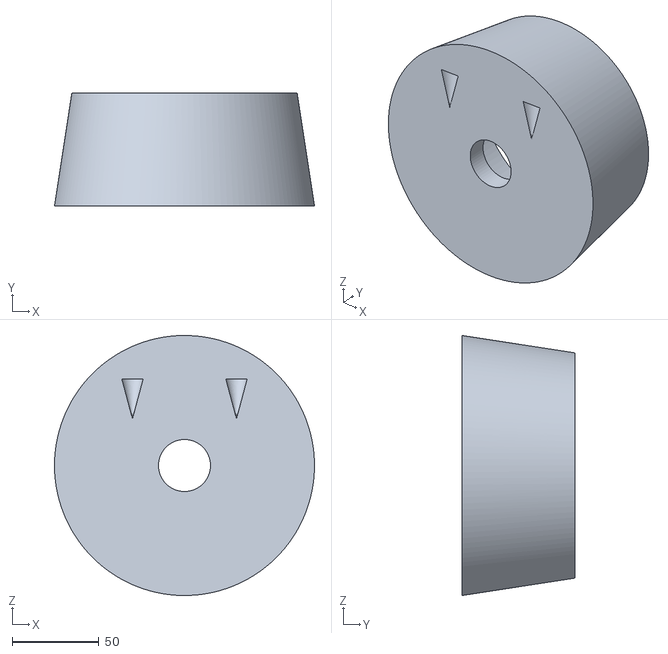
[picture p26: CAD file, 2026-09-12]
failed-iterations/loose-assets/centrifuge_base.stl
150.0 x 65.0 x 150.0

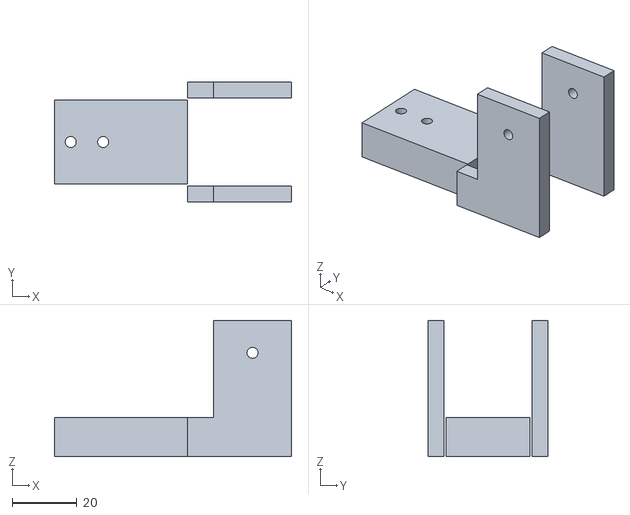
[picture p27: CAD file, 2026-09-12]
failed-iterations/BLOOM-2-fusion/stl/03_rotor_arm_PRINT_4.stl
73.0 x 37.0 x 42.0

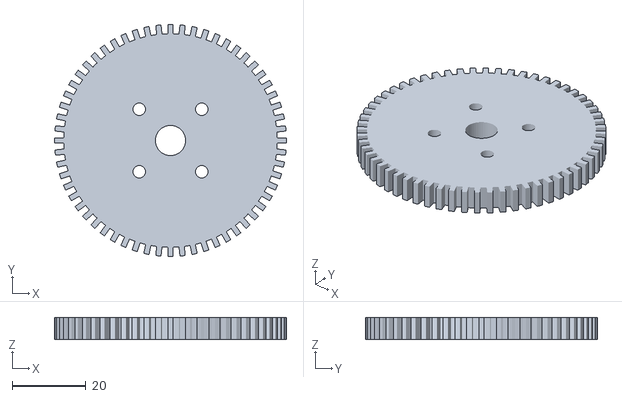
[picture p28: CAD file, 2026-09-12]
failed-iterations/BLOOM-2-fusion/stl/06b_driven_gear_60T_PROTOTYPE.stl
63.0 x 63.0 x 6.00

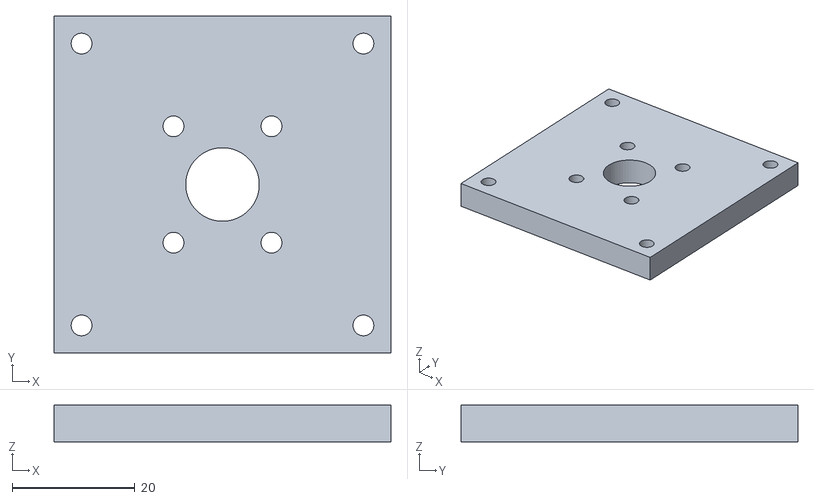
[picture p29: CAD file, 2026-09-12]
failed-iterations/BLOOM-2-fusion/stl/06a_direct_motor_plate.stl
55.0 x 55.0 x 6.00

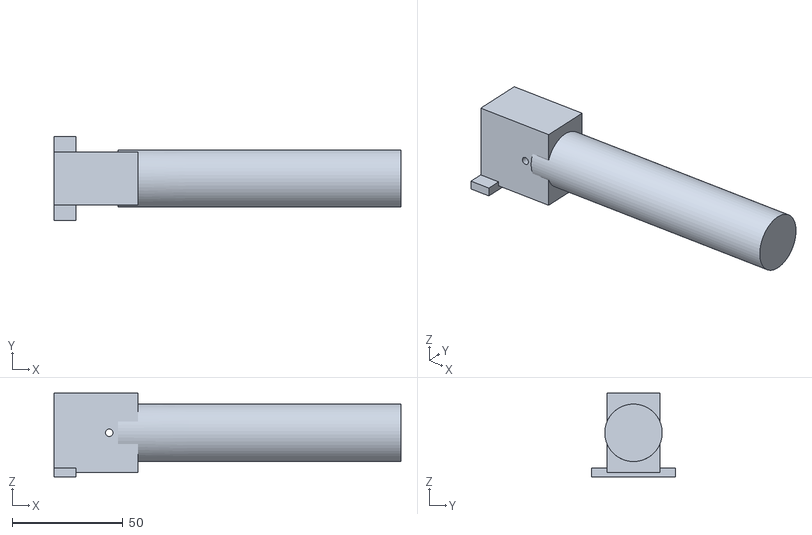
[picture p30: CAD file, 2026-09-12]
failed-iterations/BLOOM-2-fusion/stl/04_swing_bucket_PRINT_4.stl
157.0 x 38.0 x 38.0

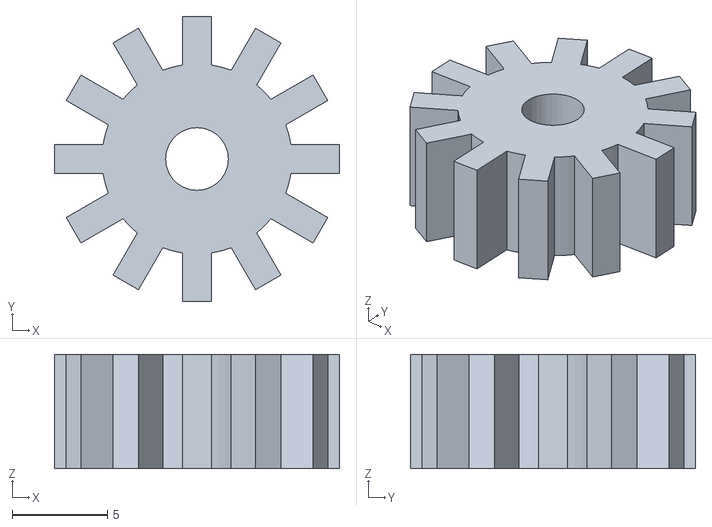
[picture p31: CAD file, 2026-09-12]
failed-iterations/BLOOM-2-fusion/stl/06b_motor_pinion_12T_PROTOTYPE.stl
15.0 x 15.0 x 6.00

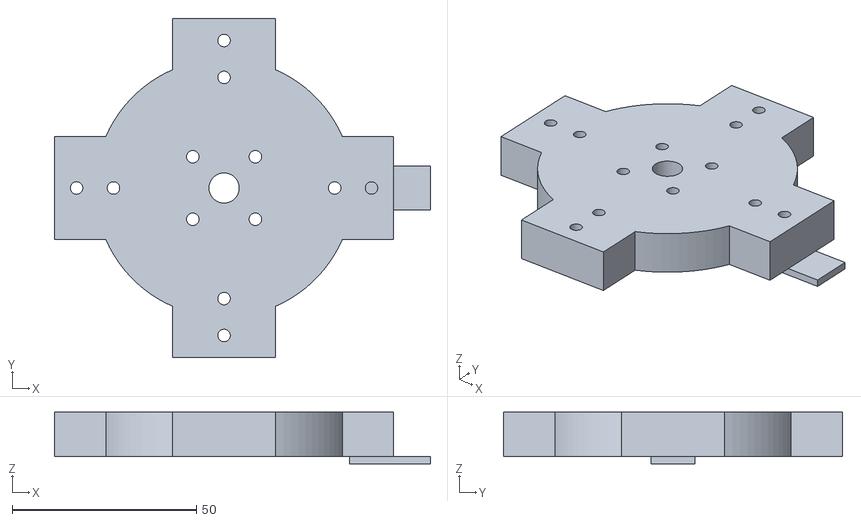
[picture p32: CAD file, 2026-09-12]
failed-iterations/BLOOM-2-fusion/stl/02_rotor_hub.stl
102.0 x 92.0 x 14.0

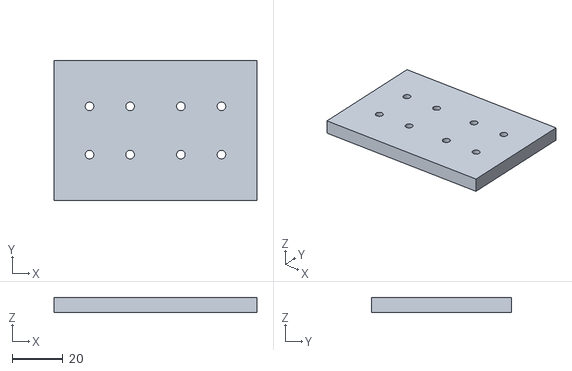
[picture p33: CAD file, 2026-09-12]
failed-iterations/BLOOM-2-fusion/stl/06b_gear_motor_plate.stl
80.0 x 55.0 x 6.00

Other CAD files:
failed-iterations/BLOOM-2-fusion/BLOOM-2_centrifuge_parametric.f3d

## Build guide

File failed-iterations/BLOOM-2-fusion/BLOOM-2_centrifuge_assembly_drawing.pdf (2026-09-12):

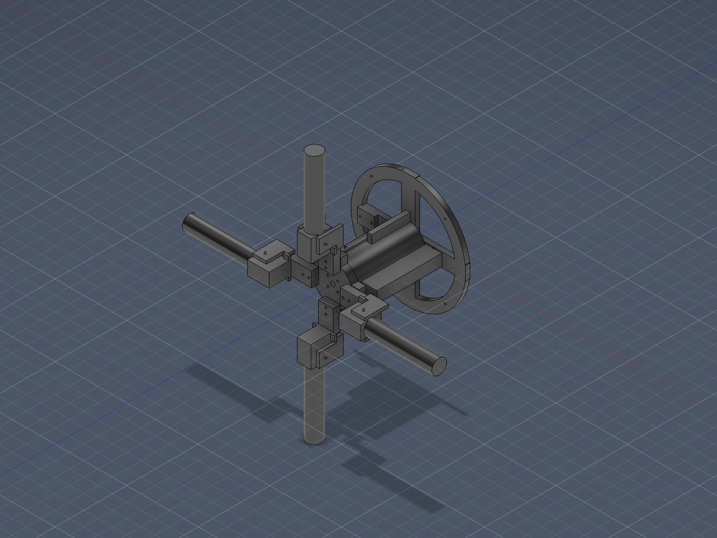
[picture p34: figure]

BLOOM-2 | PBMC Ficoll centrifuge | prototype engineering drawing | Page 1

# BLOOM-2 swinging-bucket centrifuge

## Parametric Fusion 360 prototype for four 15 mL conical tubes and Ficoll/PBMC separation

DESIGN POINT | 1545 rpm
RESULTING RCF | 400.3 x g
MID-FLUID RADIUS | 150 mm
SWING PIVOT RADIUS | 86 mm
AT-SPEED TIP RADIUS | 218 mm
MINIMUM POT ID | 466 mm
CAPACITY | 4 x 15 mL
BUCKET TRAVEL | vertical to 90 deg

Configuration shown: four buckets at the 90-degree at-speed hard stop. Optional direct and geared motor plates are excluded from the main assembly views for clarity. The rotating assembly is split into one hub, four identical arms, and four identical buckets so every printed part fits a 220 x 220 mm bed.

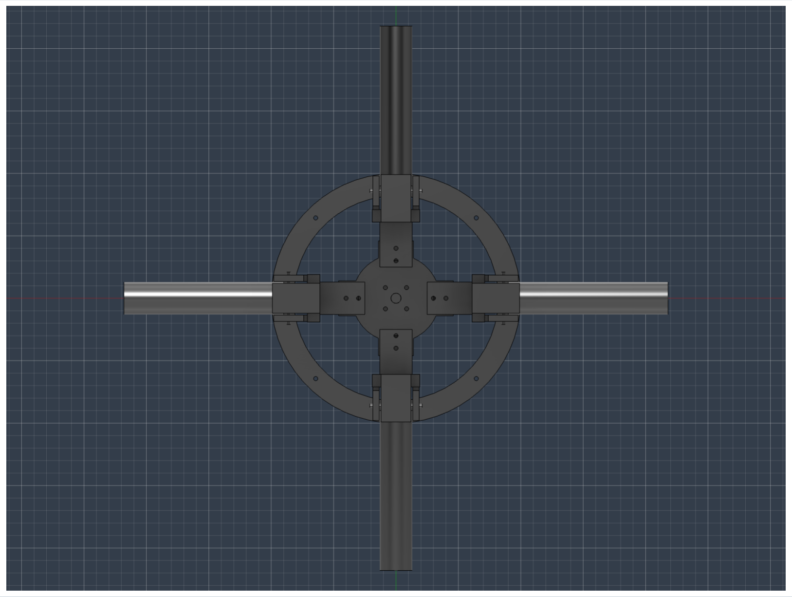
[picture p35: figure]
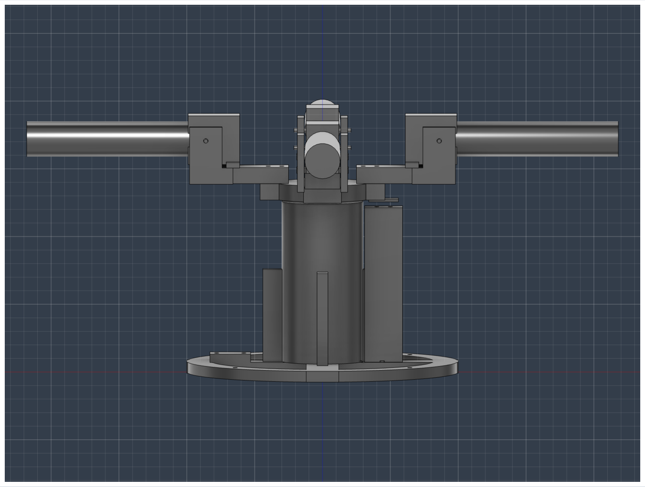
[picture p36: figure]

BLOOM-2 | PBMC Ficoll centrifuge | prototype engineering drawing | Page 2

# Assembly views and interfaces

TOP - four-fold symmetry | FRONT - bearing stack and bucket stop
01 | Dual 608ZZ tower | 22.2 mm seats, 8.3 mm through bore; light axial preload and minimum shaft overhang.
02 | Shared rotor interface | Two M3 fasteners per arm. Four-hole 24 mm BCD accepts direct coupler or driven gear without reprinting the rotor.
03 | Free swinging bucket | M3x45 tangential pivot, 0.5 mm clevis clearance, low-friction washers, and printed 90-degree stop.
04 | Instrumentation | Tall IR boss looks upward to the underside rotor target; MPU-6050 bolts rigidly to the chassis boss.
05 | Containment envelope | 436 mm diameter rotating envelope plus 15 mm wall clearance on both sides gives a 466 mm minimum clear pot ID.

BLOOM-2 | PBMC Ficoll centrifuge | prototype engineering drawing | Page 3

# Bill of materials and manufacturing notes

Category | Item | Qty | Specification | Notes
Printed | Chassis and bearing tower | 1 | PETG high infill | Includes IR pedestal and rigid MPU boss
Printed | Rotor hub | 1 | PETG solid at bolt zones | Four shared arm lands and drivetrain interface
Printed | Rotor arm | 4 | PETG high infill | Print together and mass match
Printed | Swing bucket | 4 | PETG high infill | 18.6 mm bore for 17 x 120 mm tube; print together
Printed | Direct motor plate | 1 optional | PETG | Use only for smooth direct-drive startup
Printed | Direct coupler | 1 prototype | PETG prototype | Commercial 3.17-to-8 mm coupler preferred
Printed | Gear motor plate | 1 optional | PETG | 36 mm nominal center distance
Printed | Driven gear | 1 optional | 60T module-1 prototype | Replace simplified teeth with validated involute
Printed | Motor pinion | 1 optional | 12T module-1 prototype | Replace simplified teeth with validated involute
Owned | A2212 brushless motor | 1 | 1000 KV | Ticket-specified
Owned | Sensorless ESC | 1 | 30 A | Disable brake and program smooth ramp
Owned | Battery | 1 | 2S LiPo approximately 7.4 V | Add fuse and physical disconnect
Owned | Bearing | 2 | 608ZZ 8 x 22 x 7 mm | Light preload only
Hardware | Shaft | 1 | 8 mm diameter x approximately 100-125 mm | Ground steel preferred
Hardware | Bucket pivot screw | 4 | M3 x 45 mm | Use smooth shank where possible
Hardware | Bucket pivot nylock nut | 4 | M3 | Do not pinch clevis
Hardware | Low-friction pivot washer | 8 | M3 PTFE or acetal | One each side of every bucket lug
Hardware | Arm-to-hub screw | 8 | M3 x 20 mm | With washers and nylock nuts
Hardware | Drive-interface screw | 4 | M3 x 16 mm | Shared direct/gear bolt pattern
Hardware | Motor/chassis screw set | 1 | M3 assorted | Fit selected plate and A2212 cross mount
Instrumentation | IR reflective sensor | 1 | Reflective optical tachometer | Align to rotor underside target
Instrumentation | MPU-6050 module | 1 | Rigid chassis mount | No vibration isolation
Consumable | 15 mL conical tube | 4 | 17 x 120 mm | Opposing loaded tubes matched to +/-0.1 g
Containment | Steel pot and lid | 1 | Minimum 466 mm clear inside diameter | Lid closed for every powered test
PRINT | PETG only. Print hub and arms flat. Print buckets on their side so centrifugal load runs in the layer plane. Use 6 perimeters, 8 top/bottom layers, and 70-100% infill with solid pivot/bolt zones. Print each matched set in one job.
BALANCE | Match printed buckets to +/-0.5 g. Match opposing loaded tubes to +/-0.1 g before every run. All four empty buckets must fall freely to the same hard stop.
CONTROL | Smooth spin-up, no torque steps, and coast-only stop longer than 2 minutes. Disable active brake. Use the 5:1 option only if direct drive cannot start and hold the loaded rotor smoothly.
VALIDATE | Prototype only. Containment and guarded overspeed testing precede biological use. Final functional test: four mass-matched tubes, dyed water over glycerol, 1545 rpm for 30 min, coast down. Clean interface passes; smear fails.

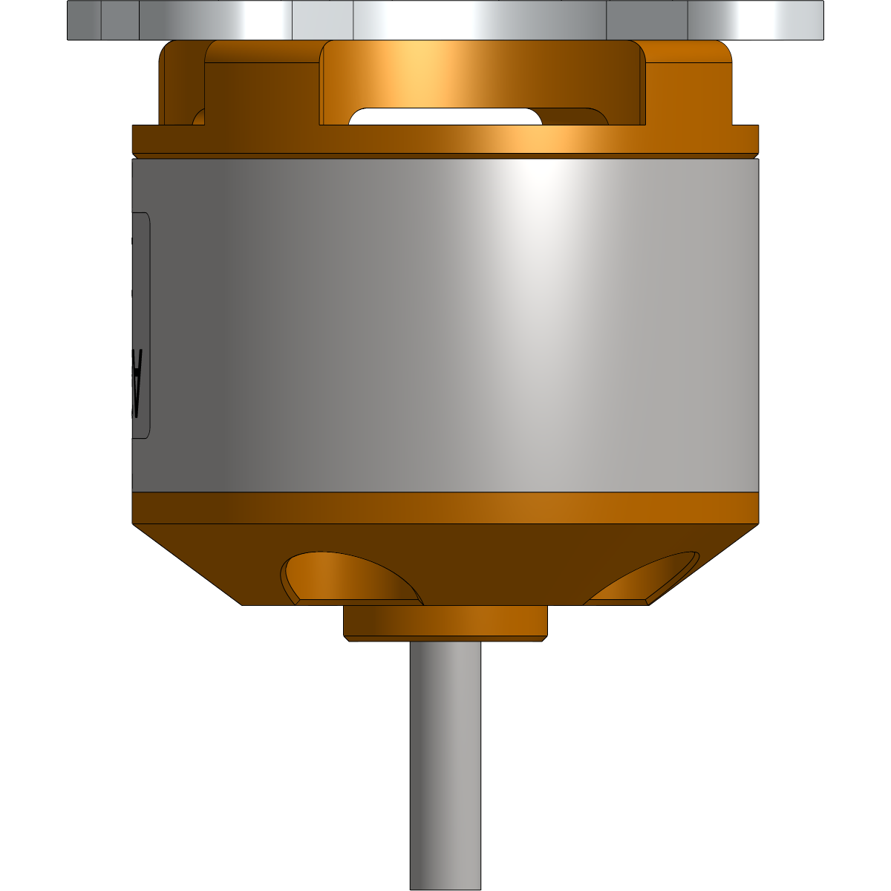
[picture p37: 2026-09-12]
renders/Brushless-Motor/_assembly/bottom.png

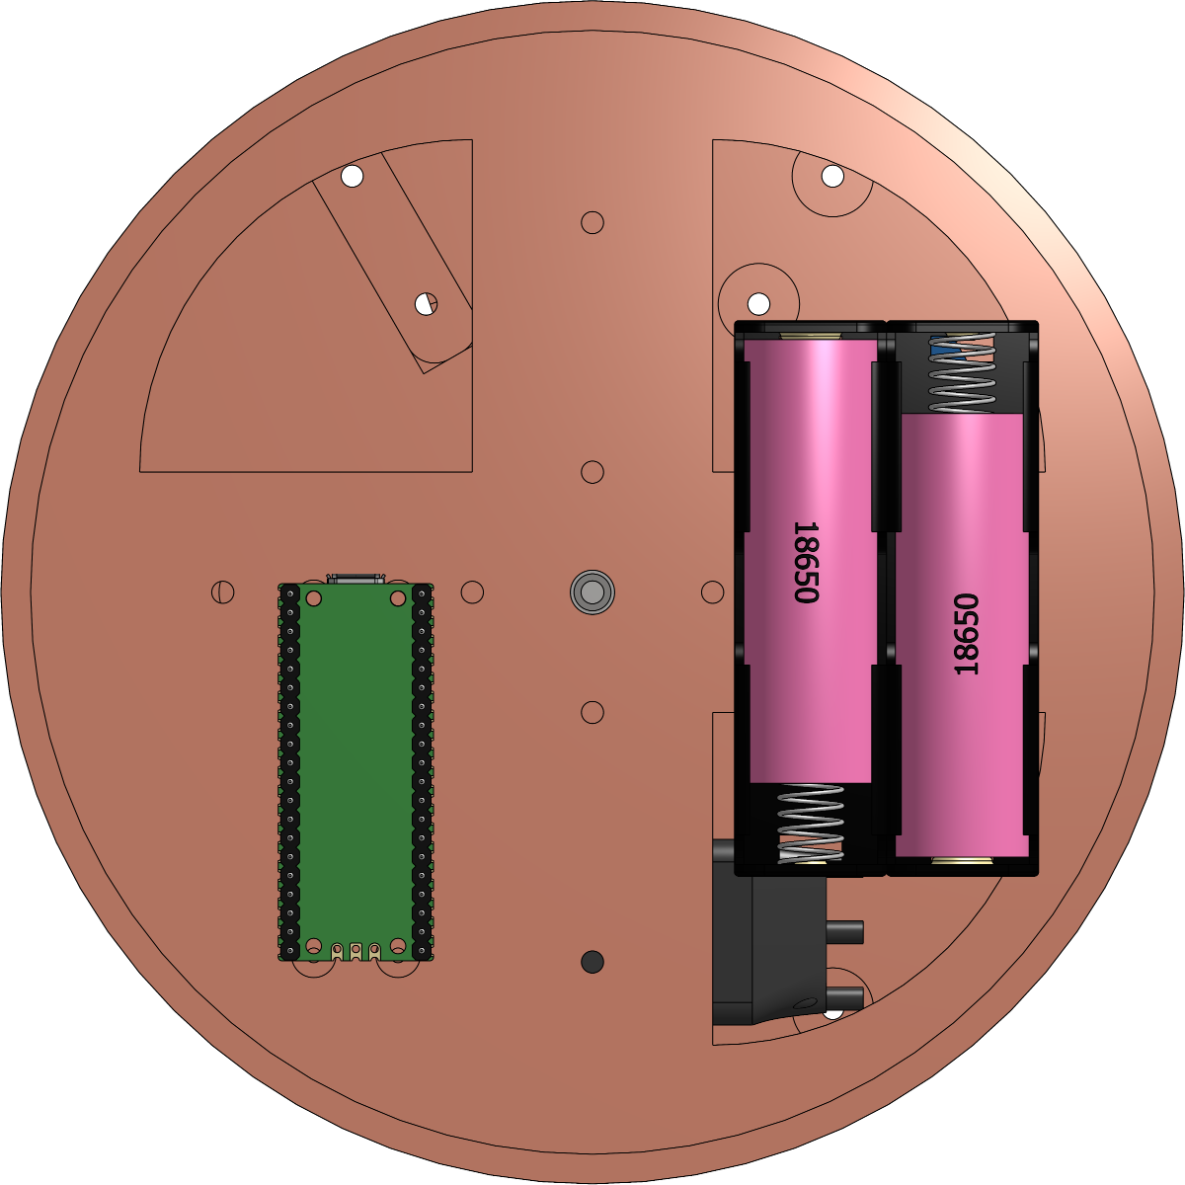
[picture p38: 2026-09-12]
renders/Centrifuge-Assembly/_assembly/bottom.png

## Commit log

2026-09-12 friday: project contracts + onshape render pipeline
    [01_chassis_bearing_tower.stl, 02_rotor_hub.stl, 03_rotor_arm_PRINT_4.stl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]
2026-09-12 collapse into one repo: picocentrifuge
    [01_chassis_bearing_tower.stl, 02_rotor_hub.stl, 03_rotor_arm_PRINT_4.stl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]
2026-09-12 onshape: filter to design tabs, 118 renders of 19 parts + 2 assemblies
2026-09-14 Update centrifuge next step to blood sample
